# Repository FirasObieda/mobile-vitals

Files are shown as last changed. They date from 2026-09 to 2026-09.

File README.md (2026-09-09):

# Mobile Vitals: AI-Powered Health Tracker with ML Predictions & Alerts

Senior Design Project — Department of Computer Engineering, University of Sharjah
(Fall 2025–2026)

**Team:** Majid M. Almheiri · Firas Obieda Abu-Bader · Abdullah Kaddoura
**Supervisor:** Dr. Bassel Soudan

## Overview

Chronic conditions like hypertension, hypoxemia, and heart-rate irregularities are
hard to catch early because the standard measurement tools (cuffs, pulse oximeters)
are manual, invasive, and non-continuous. **Mobile Vitals** is a wearable device that
continuously and non-invasively estimates **heart rate (HR), blood pressure (BP), and
blood oxygen saturation (SpO₂)** from a PPG (photoplethysmography) signal, streams
the data to the cloud, runs it through a trained ML model, and alerts the user through
a companion mobile app when a reading falls outside a normal range.

## How it works

1. A compact ESP32-based wearable captures PPG, skin temperature, and motion data.
2. Readings are sent over **Bluetooth** to the mobile app (Wi-Fi on the wearable
   proved unreliable in practice, so the design was changed to Bluetooth
   wearable↔phone, Wi-Fi phone↔cloud).
3. The app double-buffers readings and uploads them to **Firebase Firestore** every
   ~10 seconds.
4. A Firebase Cloud Function preprocesses the signal and runs it through a trained
   **Random Forest** model (selected after comparing Random Forest, XGBoost, and
   LightGBM) to predict HR, systolic/diastolic BP, and SpO₂.
5. Predictions are written back to Firestore and shown live in the app; abnormal
   readings trigger a two-tier (yellow/red) alert.

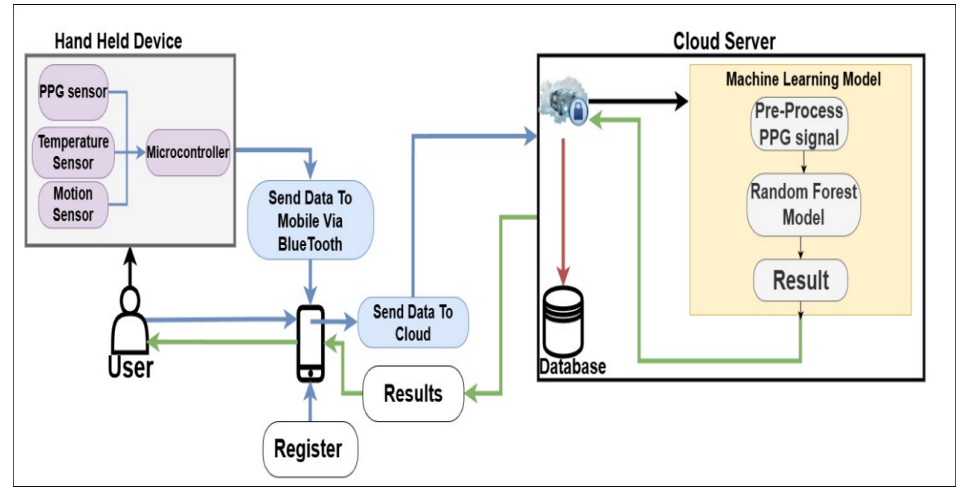
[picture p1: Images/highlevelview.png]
High level view


## Repository structure

```
firmware/     ESP32 (Arduino) firmware — sensor capture & Bluetooth transmission
backend/      Firebase Cloud Function (Python) that runs the ML inference model
mobile-app/   Flutter/FlutterFlow app — pairing, live vitals, history, alerts
ml/ppg-bp/    ML pipeline trained on the PPG-BP dataset (superseded, kept for reference)
ml/ptt-ppg/   ML pipeline trained on the PTT-PPG dataset — the one used in the final model
hardware/     KiCad PCB design files for the wearable
```

## Hardware

| Component | Model | Purpose |
|---|---|---|
| Microcontroller | Seeed Studio XIAO ESP32-C3 | Main processing unit |
| PPG sensor | MAX30105 | Captures the PPG waveform used for inference |
| Temperature sensor | MLX90614 | Contactless skin temperature (IR) |
| IMU | LSM6DS3 | Motion/orientation, for motion-artifact handling |
| Display | Waveshare 1.69" LCD | Shows HR, SpO₂, temperature, BP |
| Power | 3.7V 800mAh Li-Po + TP4056 charger | Portable power + USB charging |
| Enclosure | Custom 3D-printed casing (Onshape) | Protection & wearability |

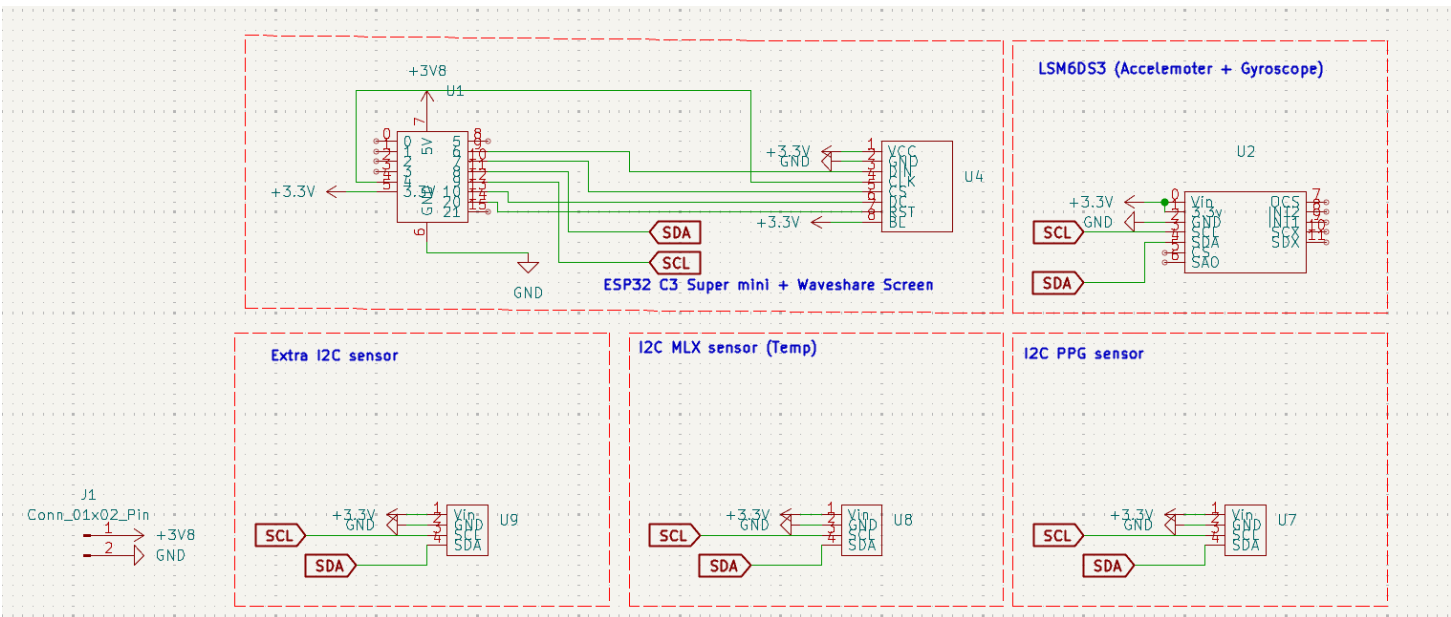
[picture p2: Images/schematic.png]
Hardware Schematic


Communication between sensors uses I²C/SPI on the wearable; wearable↔phone is
Bluetooth; phone↔cloud is Wi-Fi.

## Machine learning

Two datasets were evaluated:

- **PPG-BP** (Figshare, 657 segments / 219 subjects) — initial results were weak
  (best overall MAE ≈ 7.1, from XGBoost) and the dataset was judged not reliable
  enough.
- **PTT PPG** (PhysioNet, 22 subjects, 3,233 records across sit/run/walk) — much
  stronger results. **Random Forest** gave the best overall performance: SBP R² ≈
  0.955, DBP R² ≈ 0.921, HR R² ≈ 0.827, SpO₂ R² ≈ 0.845, overall MAE ≈ 1.31.

Preprocessing pipeline: linear interpolation for gaps → Butterworth low-pass filter
(15 Hz, 8th order) → Savitzky–Golay smoothing → normalization to [0,1] →
segmentation into 10-second windows.

## Software specifications

| Tool / Library | Version | Purpose |
|---|---|---|
| Arduino IDE | 2.3.2 | Firmware upload for the XIAO ESP32-C3 |
| Pandas | 2.2.3 | Data cleaning/manipulation |
| NumPy | 1.26.4 | Numerical computation |
| SciPy | 1.13.1 | Filtering & feature extraction |
| scikit-learn | 1.4.2 | Model training/evaluation |
| Joblib | 1.4.2 | Model persistence |
| firebase-admin (Python) | 6.4.0 | Cloud Function ↔ Firebase access |
| functions-framework | 3.6.0 | Serves the Python Cloud Function |
| cloudevents | 1.11.0 | Event handling for Cloud Functions |

## Setup

Each subfolder has more detail — start here:

- **Firmware:** open `firmware/ESP32_SOURCE_CODE.ino` in the Arduino IDE with the
  ESP32 board package installed.
- **Backend:** see the Backend section below and `backend/functions/requirements.txt`.
  Requires your own Firebase service account key (not included — see Configuration note).
- **Mobile app:** see `mobile-app/README.md`.
- **ML pipelines:** open the notebooks under `ml/ppg-bp/` or `ml/ptt-ppg/` in Jupyter.
- **Hardware:** open `hardware/wearable_device_sdp.kicad_pro` in KiCad.

### Backend (`backend/`)
```bash
cd backend/functions
python -m venv venv
source venv/bin/activate   # venv\Scripts\activate on Windows
pip install -r requirements.txt
```
This uses the Firebase Admin SDK, which needs a service account key that is **not
included** in this repo:
1. Firebase console → Project Settings → Service Accounts → Generate new private key.
2. Save it locally and point `GOOGLE_APPLICATION_CREDENTIALS` at it.
3. Never commit this file (it's covered by `.gitignore`).

Deploy: `firebase deploy --only functions` from `backend/`.

## Configuration note

This repo doesn't include environment-specific credentials (Firebase service
account key, API keys) — that's standard practice for any public repo. See the
Backend and `mobile-app/README.md` sections for how to supply your own.

## Project report

The full SDP2 report (architecture rationale, literature review, testing, and
results in detail) is available separately and covers material summarized above,
including the design evolution from the SDP1 proposal (dual PPG sensors → single
MAX30105; BME280 → MLX90614; Wi-Fi → Bluetooth for the wearable link; breadboard →
custom PCB).

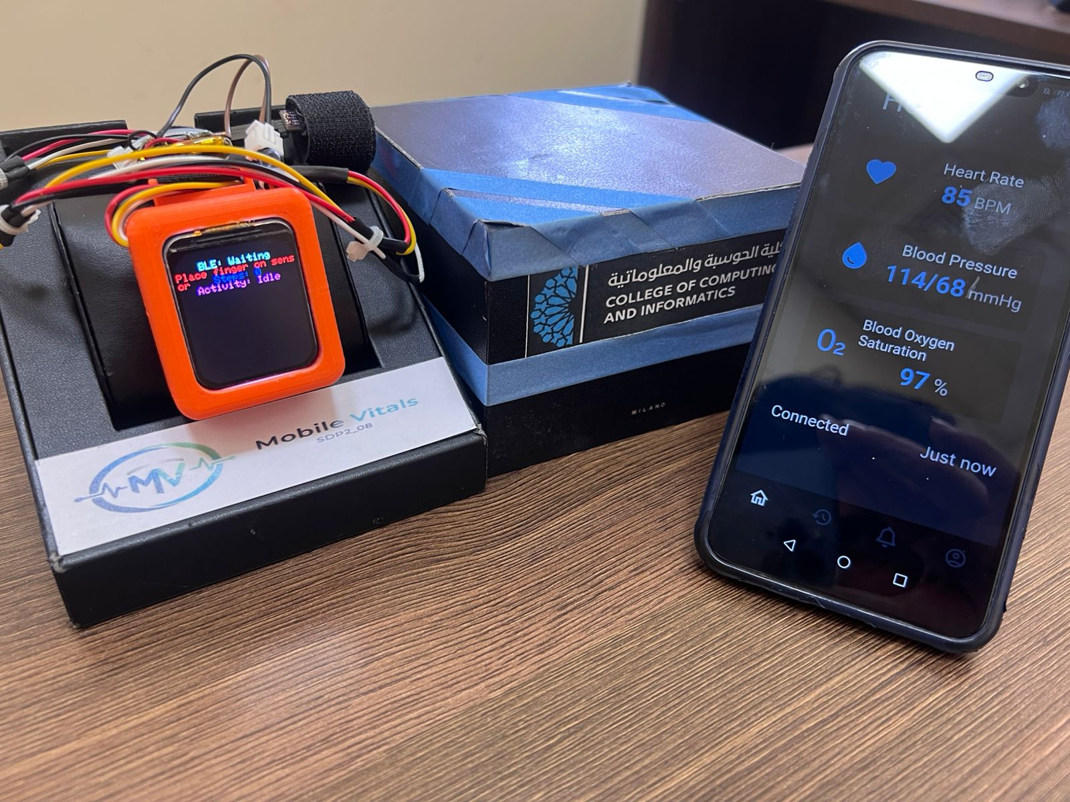
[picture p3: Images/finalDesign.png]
Final Design


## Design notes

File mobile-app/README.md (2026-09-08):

# Mobile Vitals — Mobile App

Flutter/FlutterFlow companion app for the Mobile Vitals wearable. Connects to the
wearable device over Bluetooth, buffers and uploads PPG readings to Firebase, and
displays live health vitals (HR, blood pressure, SpO₂) with a two-tier (yellow/red)
alert system.

## Stack
- **Flutter** (built with FlutterFlow)
- **Firebase**: Auth, Firestore, Cloud Functions, Storage
- Bluetooth communication with the ESP32-based wearable (see `../firmware`)

## Structure
- `lib/` — app source (screens, auth, Bluetooth pairing, device pages, alerts, history, settings, etc.)
- `firebase/` — Firestore rules, indexes, storage rules, and the project's Cloud Functions (JS + Python)
- `android/`, `ios/`, `web/` — platform targets

## Setup
1. Install [Flutter](https://docs.flutter.dev/get-started/install) (stable channel).
2. `flutter pub get`
3. Add your own Firebase client config (not included in this repo):
   - `android/app/google-services.json`
   - `ios/Runner/GoogleService-Info.plist`

   Download these from your Firebase project's console (Project Settings → Your apps).
4. This app calls the Gemini API. Provide your own key at build/run time rather than
   hardcoding it:
   ```bash
   flutter run --dart-define=GEMINI_API_KEY=your_key_here
   ```
5. Run: `flutter run`

## Firebase backend
See `firebase/functions/` for the Node.js Cloud Functions and
`firebase/cloud_functions_python/` for the Python function that runs the trained
ML model against incoming PPG data. Deploy with the Firebase CLI from `firebase/`:
```bash
firebase deploy --only functions,firestore:rules,storage
```

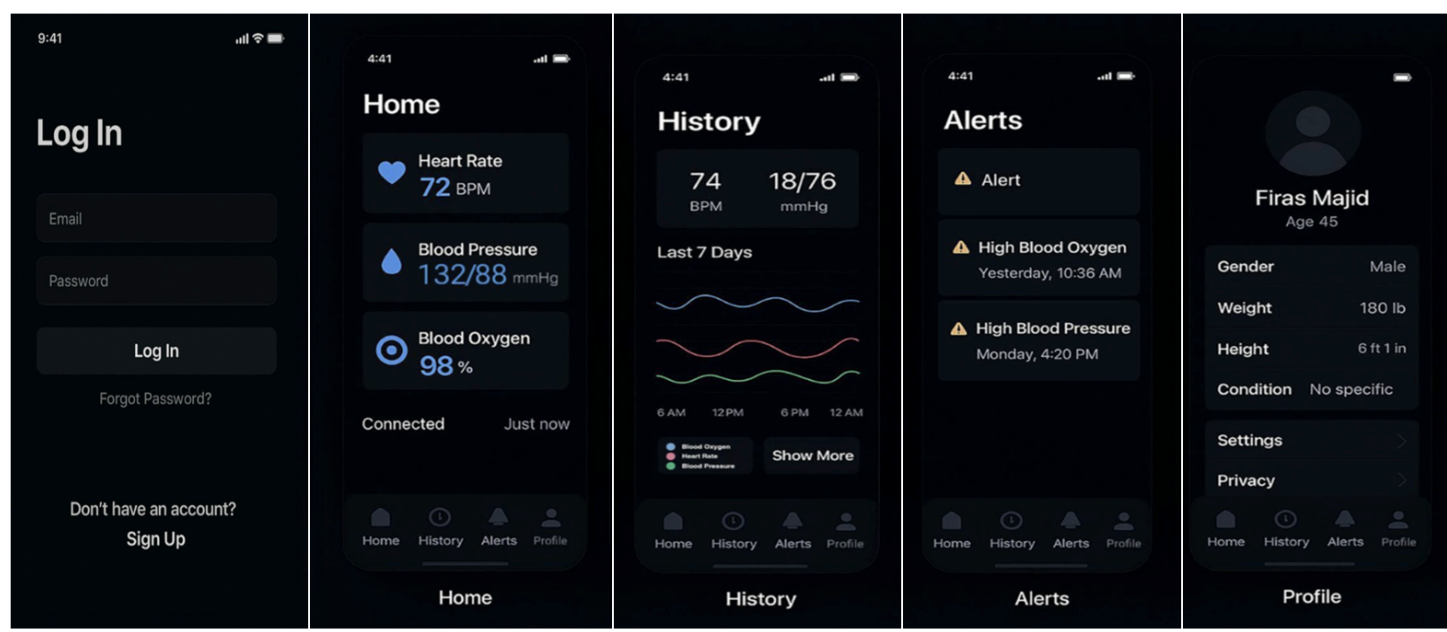
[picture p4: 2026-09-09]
Images/mobile view.png

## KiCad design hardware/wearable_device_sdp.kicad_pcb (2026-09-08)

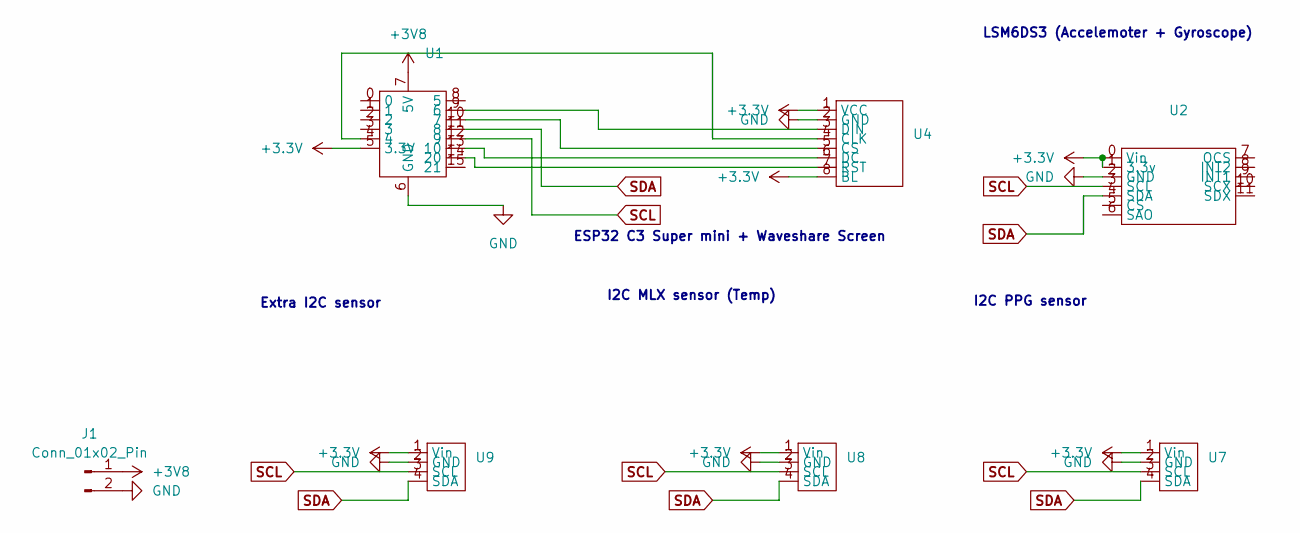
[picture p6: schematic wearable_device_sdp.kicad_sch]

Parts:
J1: Conn_01x02_Pin; PinHeader_1x02_P2.54mm_Vertical
U1: ESP32_C3_SuperMini_Flipped
U2: LSM6DS3
U4: PinHeader_1x08_P2.54mm_Vertical
U7, U9: PinHeader_1x04_P2.54mm_Vertical
U8: MLX_Temp_Sensor

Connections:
+3.3V: U1.5 (3.3V), U2.0 (Vin), U2.1 (3.3v), U4.1 (VCC), U4.8 (BL), U7.1 (Vin), U8.1 (Vin), U9.1 (Vin)
+3V8: J1.1, U1.7 (5V)
GND: J1.2, U1.6 (GND), U2.2 (GND), U4.2 (GND), U7.2 (GND), U8.2 (GND), U9.2 (GND)
unnamed: U1.9 (6), U4.3 (DIN)
unnamed: U1.10 (7), U4.5 (CS)
unnamed: U1.13 (10), U4.6 (DC)
unnamed: U1.14 (20), U4.7 (RST)
unnamed: U1.4, U4.4 (CLK)
SCL: U1.12 (9), U2.3 (SCL), U7.3 (SCL), U8.3 (SCL), U9.3 (SCL)
SDA: U1.11 (8), U2.4 (SDA), U7.4 (SDA), U8.4 (SDA), U9.4 (SDA)

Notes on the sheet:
Extra I2C sensor
I2C MLX sensor (Temp)
ESP32 C3 Super mini + Waveshare Screen
I2C PPG sensor
LSM6DS3 (Accelemoter + Gyroscope)

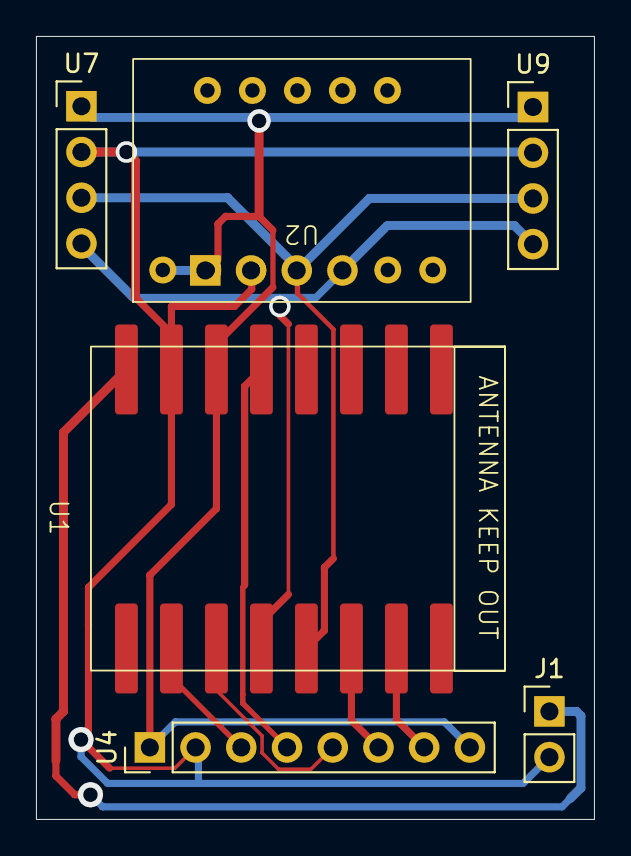
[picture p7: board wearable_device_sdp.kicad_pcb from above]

Board: 2 copper layers, 31.0 x 43.5 mm, 7 parts (1 on the bottom side), 10 nets.

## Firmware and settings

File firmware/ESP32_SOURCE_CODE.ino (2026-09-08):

#include <Wire.h>
#include "MAX30105.h"
#include "MPU9250_asukiaaa.h"
#include <Adafruit_MLX90614.h>
#include <SPI.h>
#include <Adafruit_GFX.h>
#include <Adafruit_ST7789.h>
#include <math.h>
#include <BLEDevice.h>
#include <BLEServer.h>
#include <BLEUtils.h>
#include <BLE2902.h>

// --- Sensors ---
MAX30105 particleSensor;
MPU9250_asukiaaa imu;
Adafruit_MLX90614 mlx = Adafruit_MLX90614();

// --- Display ---
#define TFT_CS   7
#define TFT_RST  20
#define TFT_DC   10
Adafruit_ST7789 tft = Adafruit_ST7789(TFT_CS, TFT_DC, TFT_RST);

// --- BLE ---
#define SERVICE_UUID         "12345678-1234-1234-1234-1234567890ab"
#define CHARACTERISTIC_IR    "abcd0001-5678-90ab-cdef-1234567890ab"
#define CHARACTERISTIC_RED   "abcd0002-5678-90ab-cdef-1234567890ab"
#define CHARACTERISTIC_GREEN "abcd0003-5678-90ab-cdef-1234567890ab"

BLECharacteristic *irChar;
BLECharacteristic *redChar;
BLECharacteristic *greenChar;
bool deviceConnected = false;

// --- Constants ---
const uint32_t FINGER_THRESHOLD = 50000;
const unsigned long SAMPLE_INTERVAL_US = 2000;
const unsigned long DISPLAY_INTERVAL_MS = 500;
const int yOffset = 24;       
const int lineHeight = 16;    

// --- MPU variables ---
float aX, aY, aZ, aSqrt;
int stepCount = 0;
float lastAccelMag = 0;
unsigned long lastStepTime = 0;
const float STEP_THRESHOLD = 1.15;
const unsigned long STEP_DEBOUNCE_MS = 400;
String activityStatus = "Idle";

// --- Timing ---
unsigned long lastSampleTime = 0;
unsigned long lastDisplayTime = 0;

// --- BLE Callbacks ---
class MyServerCallbacks : public BLEServerCallbacks {
  void onConnect(BLEServer* pServer) { deviceConnected = true; }
  void onDisconnect(BLEServer* pServer) { deviceConnected = false; }
};

// --- Center Text Helper ---
void centerText(String text, int y, uint16_t color = ST77XX_WHITE) {
  int16_t x1, y1;
  uint16_t w, h;
  tft.getTextBounds(text, 0, y, &x1, &y1, &w, &h);
  int16_t x = (tft.width() - w) / 2;
  tft.setCursor(x, y);
  tft.setTextColor(color);
  tft.print(text);
}

// --- Step/Activity Detection ---
void updateStepCounter(float aX, float aY, float aZ) {
  float accelMag = sqrt(aX * aX + aY * aY + aZ * aZ);
  unsigned long now = millis();

  if (accelMag > STEP_THRESHOLD && lastAccelMag <= STEP_THRESHOLD) {
    if (now - lastStepTime > STEP_DEBOUNCE_MS) {
      stepCount++;
      lastStepTime = now;
    }
  }
  lastAccelMag = accelMag;

  if (accelMag < 1.05) activityStatus = "Idle";
  else if (accelMag < 1.5) activityStatus = "Walking";
  else activityStatus = "Running";
}

// --- Display Update ---
void updateDisplay(uint32_t ir, uint32_t red, uint32_t green, float mlxTemp, bool fingerDetected) {
  tft.fillScreen(ST77XX_BLACK);
  tft.setTextSize(2);
  int y = yOffset;

  centerText(deviceConnected ? "BLE: Connected" : "BLE: Waiting", y, ST77XX_CYAN); y += lineHeight;
  if (fingerDetected) {
    centerText("Finger Detected ✅", y, ST77XX_GREEN); y += lineHeight;
    centerText("IR: " + String(ir), y, ST77XX_RED); y += lineHeight;
    centerText("RED: " + String(red), y, ST77XX_ORANGE); y += lineHeight;
    centerText("GREEN: " + String(green), y, ST77XX_GREEN); y += lineHeight;
    centerText("Skin Temp: " + String(mlxTemp) + " C", y, ST77XX_YELLOW); y += lineHeight;
  } else {
    centerText("Place finger on sensor", y, ST77XX_RED); y += lineHeight;
  }
  centerText("Steps: " + String(stepCount), y, ST77XX_BLUE); y += lineHeight;
  centerText("Activity: " + activityStatus, y, ST77XX_MAGENTA);
}

void setup() {
  Serial.begin(115200);
  Wire.begin(8, 9);
  Wire.setClock(100000);

  // MAX30105
  if (!particleSensor.begin(Wire, I2C_SPEED_STANDARD)) {
    Serial.println("MAX30105 not found!");
    while (1);
  }
  particleSensor.setup();
  particleSensor.setPulseAmplitudeRed(0x1F);
  particleSensor.setPulseAmplitudeIR(0x1F);
  particleSensor.setPulseAmplitudeGreen(0x1F);

  // MPU
  imu.beginAccel();
  imu.beginGyro();

  // MLX
  if (!mlx.begin()) {
    Serial.println("MLX90614 not found!");
  }

  // Display
  tft.init(240, 280); // Important: fix resolution to match ST7789V2
  tft.setRotation(0);
  tft.fillScreen(ST77XX_BLACK);

  // BLE
  BLEDevice::init("Mobile Vitals Wearable");
  BLEServer *pServer = BLEDevice::createServer();
  pServer->setCallbacks(new MyServerCallbacks());
  BLEService *pService = pServer->createService(SERVICE_UUID);

irChar = pService->createCharacteristic(
    CHARACTERISTIC_IR,
    BLECharacteristic::PROPERTY_READ | BLECharacteristic::PROPERTY_NOTIFY);

redChar = pService->createCharacteristic(
    CHARACTERISTIC_RED,
    BLECharacteristic::PROPERTY_READ | BLECharacteristic::PROPERTY_NOTIFY);

greenChar = pService->createCharacteristic(
    CHARACTERISTIC_GREEN,
    BLECharacteristic::PROPERTY_READ | BLECharacteristic::PROPERTY_NOTIFY);

  irChar->addDescriptor(new BLE2902());
  redChar->addDescriptor(new BLE2902());
  greenChar->addDescriptor(new BLE2902());

  pService->start();
  BLEAdvertising *pAdvertising = BLEDevice::getAdvertising();
  pAdvertising->start();

  Serial.println("System ready.");
}

void loop() {
  unsigned long nowMicros = micros();
  if (nowMicros - lastSampleTime >= SAMPLE_INTERVAL_US) {
    lastSampleTime = nowMicros;

    uint32_t ir = particleSensor.getIR();
    uint32_t red = particleSensor.getRed();
    uint32_t green = particleSensor.getGreen();
    bool fingerDetected = ir > FINGER_THRESHOLD;

    // Read MLX
    float mlxTemp = mlx.readObjectTempC();

    // Read MPU
    if (imu.accelUpdate() == 0) {
      aX = imu.accelX();
      aY = imu.accelY();
      aZ = imu.accelZ();
      updateStepCounter(aX, aY, aZ);
    }

    // BLE notify
    if (deviceConnected && fingerDetected) {
      char payload[40];
      int len = snprintf(payload, sizeof(payload), "%lu,%lu,%lu\n", ir, red, green);
      if (len > 0) {
        irChar->setValue((uint8_t*)payload, len);
        irChar->notify();
      }
      redChar->setValue((uint8_t*)&red, sizeof(red)); redChar->notify();
      greenChar->setValue((uint8_t*)&green, sizeof(green)); greenChar->notify();
    }

    // Serial
    Serial.printf("BLE: %s | IR=%lu RED=%lu GREEN=%lu | Temp=%.1f C | Steps=%d | Activity=%s\n",
                  deviceConnected ? "Connected" : "Waiting",
                  ir, red, green, mlxTemp+7, stepCount, activityStatus.c_str());

    // Update display every DISPLAY_INTERVAL_MS
    if (millis() - lastDisplayTime >= DISPLAY_INTERVAL_MS) {
      lastDisplayTime = millis();
      updateDisplay(ir, red, green, mlxTemp, fingerDetected);
    }
  }
}

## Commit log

2026-09-08 Initial commit: Mobile Vitals wearable health tracker
    [ppg_bp_features_extended.csv, ppg_features_all_subjects.csv, wearable_device_sdp.kicad_pcb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]
2026-09-09 Add images to README for wearable device
    Added images of the assembled wearable device and schematic to the README.
